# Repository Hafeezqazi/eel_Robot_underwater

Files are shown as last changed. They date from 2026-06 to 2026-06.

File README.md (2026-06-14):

# 🐟 Bio-Inspired Underwater Eel Robot

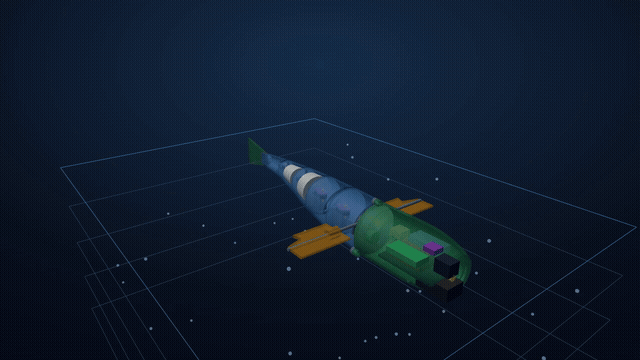
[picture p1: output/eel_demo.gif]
Eel robot swimming and diving


*Travelling-wave swim, a bow-plane dive through the depth rings, and a see-through
body showing the internals (battery, ESP32, foam, keel) — a deterministic
**HyperFrames** render of the actual 3D scene (`cad/make_video.py`).
▶ [Full-quality MP4](output/eel_demo.mp4).*

### 🖥️ [▶ Open the live 3D viewer &amp; datasheet](https://hafeezqazi.github.io/eel_Robot_underwater/)
*Runs right in your browser — interactive 3D model, internals, motion, and all the
engineering numbers. No install. (Or open `eel_design.html` / `eel_viewer.html`
straight from the repo root.)*

A ~50 cm anguilliform (eel-style) underwater robot: a free-flooding, segmented
body that swims with a travelling body wave, dives with bow planes, and carries a
camera + light in a sealed head. Tethered, 3D-printable, desk/pool scale.

This repo is a **complete digital design package** — parametric CAD,
first-principles engineering analysis, ESP32 control firmware, full build docs,
and a researched BOM. The whole pipeline regenerates and self-checks at
**28/28** (`python verify_all.py`). It is a *verified design*, not yet a
physically-built robot.

### Start here
- 📄 **[Full design report](PROJECT_REPORT.md)** — the story + every decision, in plain language.
- 🖥️ **[Interactive viewer + datasheet](https://hafeezqazi.github.io/eel_Robot_underwater/)** — live in your browser (3D model, internals, all the numbers; no install), or open [`eel_design.html`](eel_design.html) from the repo root.
- 🛠️ **[Build guide](docs/build_guide.md)** · 🧾 **[BOM](docs/BOM.md)** · 🏭 **[Manufacturing](docs/manufacturing.md)** · 🔌 **[Wiring](docs/wiring_pinout.md)**

### Reproduce it
```bash
pip install cadquery numpy matplotlib
python verify_all.py          # regenerates all parts + reports, checks 28/28
```

### Headline numbers (predicted — confirm in the tank)
| | |
|---|---|
| Size / mass | 500 × 70 mm / ~390 g dry |
| Stability | neutral buoyancy, roll +8 mm, ~2° trim |
| Cruise (predicted) | ~0.53 m/s, 2 Hz tail-beat, Strouhal 0.22–0.44 |
| Depth | rated 2 m (head bay good to ~84 m before buckling) |
| Power | ~6.7 W avg, sized for ~4 A peak |

### Status
✅ Digital design complete + validated (CAD, analysis, firmware source, docs, BOM).
⬜ Physical build remains (compile/flash firmware, buy exact parts, print, seal,
wet-test) — these need hardware, by design. See the report's "done vs. next".

---
*Built as a code-driven parametric design. Single source of truth:
[`cad/params.py`](cad/params.py).*

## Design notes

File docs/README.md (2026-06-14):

# Bio-Inspired Underwater Eel Robot

A from-scratch design package for an **anguilliform (eel) underwater robot** —
a ~500 mm desk/pool prototype that swims by undulating a chain of **5 revolute
joints** (front 3 servo-driven), with **bow dive planes for active depth
control (3-D diving)** and an **FPV camera + LED headlight** looking out a
clear nose window — so it's a usable mini-ROV, not just a swimmer. Everything
here is parametric and runnable: change one number in `cad/params.py` and the
CAD geometry, the physics sizing, and the gait all update together.

> Scope: desk/pool prototype tier — ~50 cm, shallow (<2 m), tethered,
> 3D-printed, hobby metal-gear servos. Re-parameterize to scale up.

---

## 1. What's in the box

```
eel_robot/
├─ cad/                 CadQuery parametric CAD (run these to get STEP/STL)
│  ├─ params.py         SINGLE SOURCE OF TRUTH — all dimensions & physics
│  ├─ joints.py         revolute joint hardware (tongue + clevis + pin)
│  ├─ body.py           tapered free-flooding body segments (seg1..seg5)
│  ├─ head_bay.py       sealed dry electronics bay + O-ring lid
│  ├─ assembly.py       full kinematic chain → STEP / SVG / print STLs
│  ├─ dive_planes.py    bow dive planes (active depth control → 3-D)
│  ├─ skin.py           flexible TPU skin sleeve (covers joint gaps)
│  ├─ test_rig.py       bollard-thrust test cradle (bench tool)
│  ├─ test_coupons.py   fit/seal coupons (servo, potting cup, O-ring)
│  ├─ ballast.py        keel strap, trim rail/carrier, foam retainer
│  ├─ tail_flexure.py   3 TPU passive-tail flexure variants (bench-pick)
│  ├─ hull_solid.py     watertight single hull for CFD meshing
│  ├─ render.py         top-view + dive-plane previews (QA only)
│  ├─ render3d.py       shaded 3-D isometric + orthographic renders
│  ├─ web_viewer.py     → output/eel_viewer.html (interactive browser 3-D)
│  └─ design_page.py    → output/eel_design.html (ALL-IN-ONE shareable page)
├─ analysis/
│  ├─ sizing.py         drag, buoyancy/ballast, gait, torque, power budget
│  ├─ structures.py     pressure-hull stress, buckling depth, pin shear, seal
│  ├─ swim_sim.py       Lighthill self-propulsion + swim_cycle.gif
│  ├─ dive.py           dive-plane lift, min dive speed, descent rate
│  ├─ stability.py      CG vs CB, roll + trim, foam/keel sizing
│  ├─ power.py          peak current, brownout, tether voltage drop
│  ├─ tail_stiffness.py passive-tail spring rate / TPU-flexure thickness
│  └─ dive_linkage.py   dive 4-bar: 1:1 kinematics + servo holding torque
├─ firmware/
│  ├─ gait.py           anguilliform gait generator (Python reference)
│  └─ eel_gait.ino      ESP32 port: PCA9685 + 4 servos + leak cutoff
├─ cfd/                 OpenFOAM steady drag case (you run the solve)
│  ├─ case_setup.py     stage hull STL + report Reynolds / drag
│  ├─ 0/ constant/ system/   standard simpleFoam dictionaries
│  └─ README.md         how to run + read the drag coefficient
├─ docs/
│  ├─ README.md         this file
│  ├─ BOM.md            bill of materials (AliExpress link on every line)
│  ├─ manufacturing.md  materials, print settings, tolerances, sealing
│  ├─ build_guide.md    step-by-step build + build-readiness checklist
│  ├─ joints.md         joint / DOF reference table
│  ├─ wiring_pinout.md  pin-level wiring table (matches eel_gait.ino)
│  └─ wiring.drawio     editable electronics block diagram
├─ verify_all.py       run the whole pipeline, report PASS/FAIL (one command)
└─ output/             all generated artifacts (STEP, STL, SVG, PNG, GIF, TXT)
```

---

## 2. Quick start

```bash
# one-time: install the CAD kernel (large — pulls OpenCascade)
python -m pip install cadquery numpy matplotlib

# regenerate everything
cd cad
python params.py        # prints the parameter/geometry summary
python joints.py        # output/joint_demo.{step,stl}
python head_bay.py      # output/head.stl, output/lid.stl
python body.py          # output/test_seg1.stl, test_seg5.stl
python assembly.py      # output/eel_straight.*, eel_swim.*, print_*.stl
python dive_planes.py   # output/print_dive_plane.stl, print_dive_shaft.stl
python skin.py          # output/print_skin.stl  (flexible sleeve)
python test_rig.py      # output/print_test_rig.stl
python hull_solid.py    # output/cfd_hull.{stl,step}
python render.py        # output/preview_*.png  (top + dive views)
python render3d.py      # output/render3d_iso.png, render3d_views.png (shaded 3-D)
python joint_detail.py  # output/joint_detail.png (exploded joint close-up)
python web_viewer.py    # output/eel_viewer.html (interactive, animated, browser)

cd ../analysis
python sizing.py        # output/sizing_report.txt
python structures.py    # output/structures_report.txt
python swim_sim.py      # predicted cruise speed + output/swim_cycle.gif
python dive.py          # output/dive_report.txt  (dive performance)
python stability.py     # output/stability_report.txt  (CG/CB, roll, trim, foam/keel)
python power.py          # output/power_report.txt  (peak current, tether drop)
python tail_stiffness.py # output/tail_stiffness_report.txt  (flexure/band sizing)
python dive_linkage.py   # output/dive_linkage_report.txt  (1:1 kinematics + torque)

cd ../firmware && python gait.py       # prints the servo command table

# optional CFD drag study (needs OpenFOAM on Linux/WSL/Docker):
cd ../cfd && python case_setup.py && ./Allrun
```

Or just run everything and check it all still passes:

```bash
python verify_all.py     # runs every script in order → PASS/FAIL table
```

Open `output/eel_swim.step` in any CAD viewer (FreeCAD, Fusion, Onshape) to
inspect the articulated assembly; slice `output/print_*.stl` to 3D-print.

> Tested with Python 3.13 + cadquery 2.7.0. If `pip install cadquery` fails on
> your Python, create a 3.11/3.12 virtual-env — OCP wheels are most reliable
> there.

---

## 3. Key results (current parameters)

> **Predicted, not validated.** Every performance number below (speed, drag,
> Strouhal, dive, descent) is a first-order *estimate* from the analysis scripts
> — assumed `Cd`, Lighthill EBT with a 0.5 derate, **no CFD solve and no wet
> test**. Treat them as design targets to confirm in the tank, not measured
> results. Geometry/mass/buoyancy/torque are computed from the CAD and are firmer.

| Quantity | Value | Source |
|---|---|---|
| Length × max dia | 500 × 70 mm (nose truncated at z=18 for the window) | `params.py` |
| DOF | 3 driven + 2 passive body joints + dive planes (4 servos total) | `params.py` |
| Joint travel | ±28° | `params.py` |
| Payload | analog FPV camera + dimmable LED headlight behind a Ø30 acrylic nose window | `head_bay.py` |
| Displaced volume | ~1105 cm³ | `sizing.py` |
| Dry mass | ~390 g (4 servos + camera + LED) | `sizing.py` |
| Inherent buoyancy (free-flood) | +150 g positive (add ballast to neutral) | `sizing.py` |
| Cruise drag @ 0.3 m/s | ~17 mN | `sizing.py` |
| Tail-beat frequency | 2.0 Hz (cruise) | `params.py` |
| Cruise joint amplitude | 7° (28° max in reserve) | `params.py` |
| Predicted cruise speed | ~0.53 m/s (1.1 BL/s) realistic; 1.07 m/s EBT upper bound | `swim_sim.py` |
| Strouhal | 0.22 at the EBT speed; ~0.44 at the derated speed (pool-tune) | `swim_sim.py` |
| Dive planes | 63 cm² (2 fins, 1 servo), ±25°, root clear of hull+skin | `dive.py` |
| Min dive speed / descent rate | 0.24 m/s / ~0.5 m/s | `dive.py` |
| Servo torque margin | ~40× (at full ±28° travel) | `sizing.py` |
| Electrical load | ~6.7 W incl. 2 W light (0.91 A @ 7.4 V) | `sizing.py` |
| Pressure-hull collapse depth | ~84 m (rated 2 m) | `structures.py` |
| Joint-pin shear SF | ~13× | `structures.py` |
| O-ring squeeze | 25% (ideal 15–30%) | `structures.py` |
| Hull vol. CAD vs analytic | 1105.9 vs 1104.8 cm³ (0.1%) | cross-check |

Design previews (straight, mid-stroke, and the animated swim cycle):

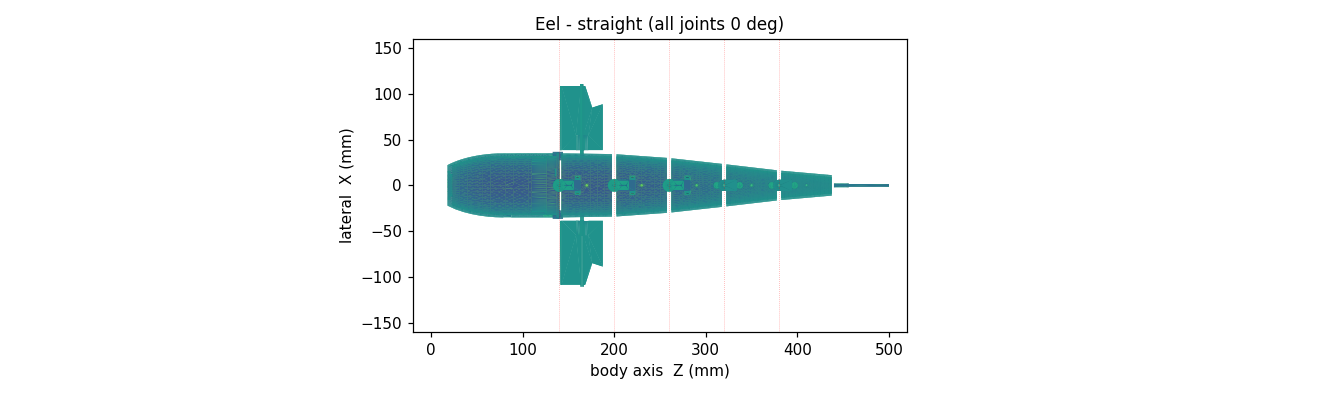
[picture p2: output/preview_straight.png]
straight

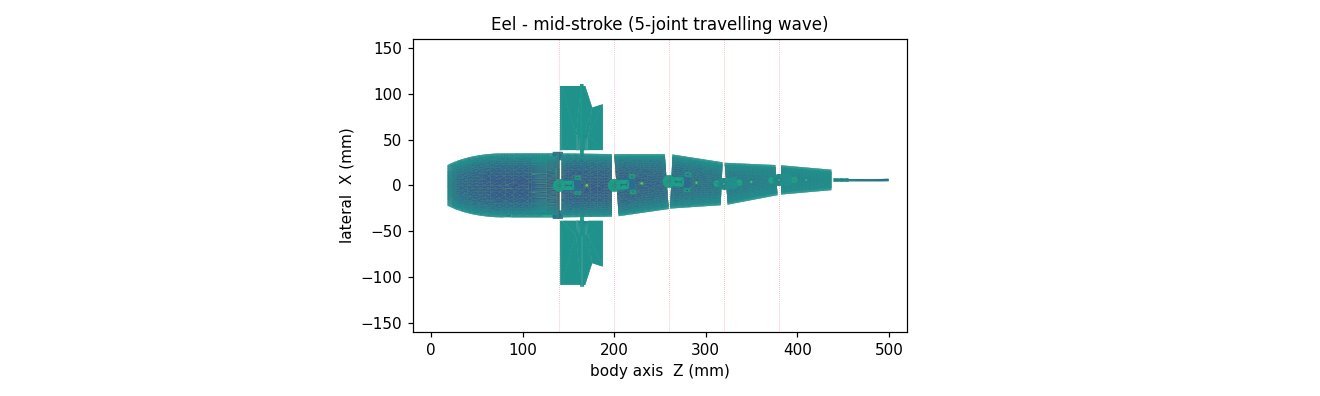
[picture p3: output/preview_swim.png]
swim

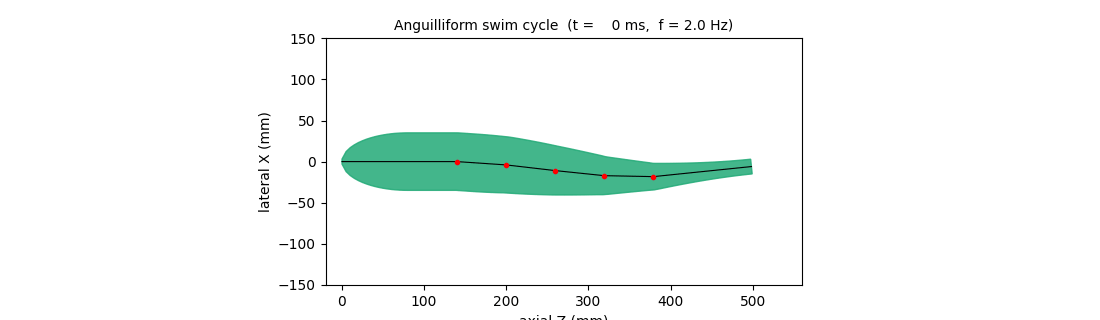
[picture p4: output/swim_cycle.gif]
cycle

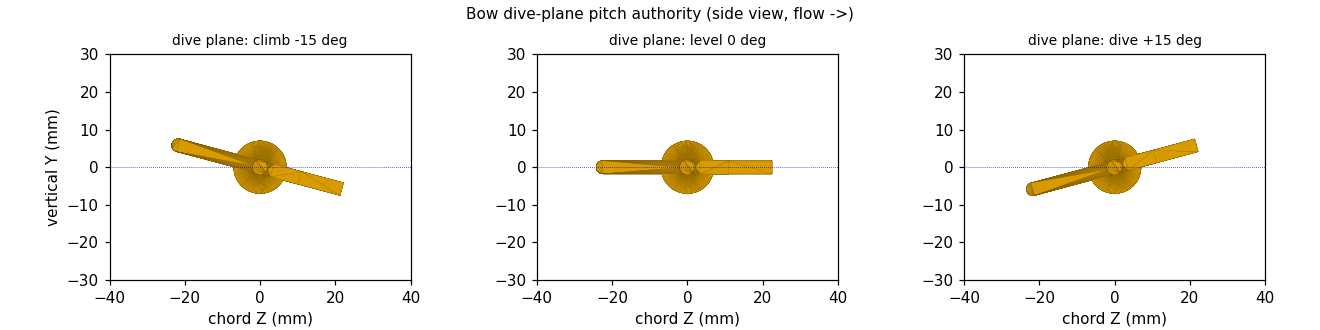
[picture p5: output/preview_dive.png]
dive


Shaded 3-D (`cad/render3d.py`):

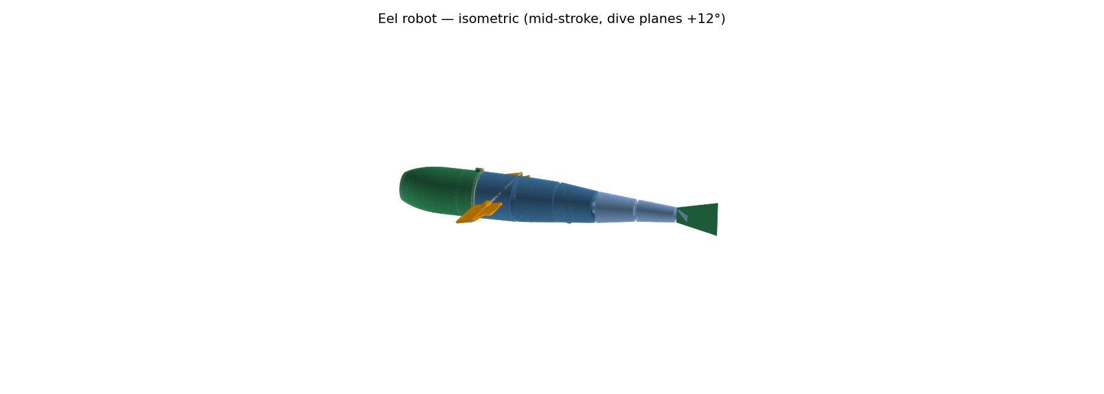
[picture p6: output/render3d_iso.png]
iso

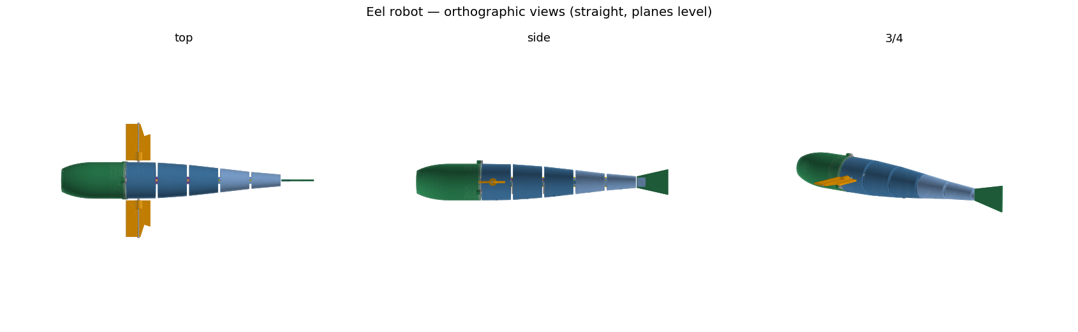
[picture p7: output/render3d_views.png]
views


How one joint goes together (`cad/joint_detail.py`) — pin = hinge, servo+horn
drives the front 3, rubber band springs the back 2:

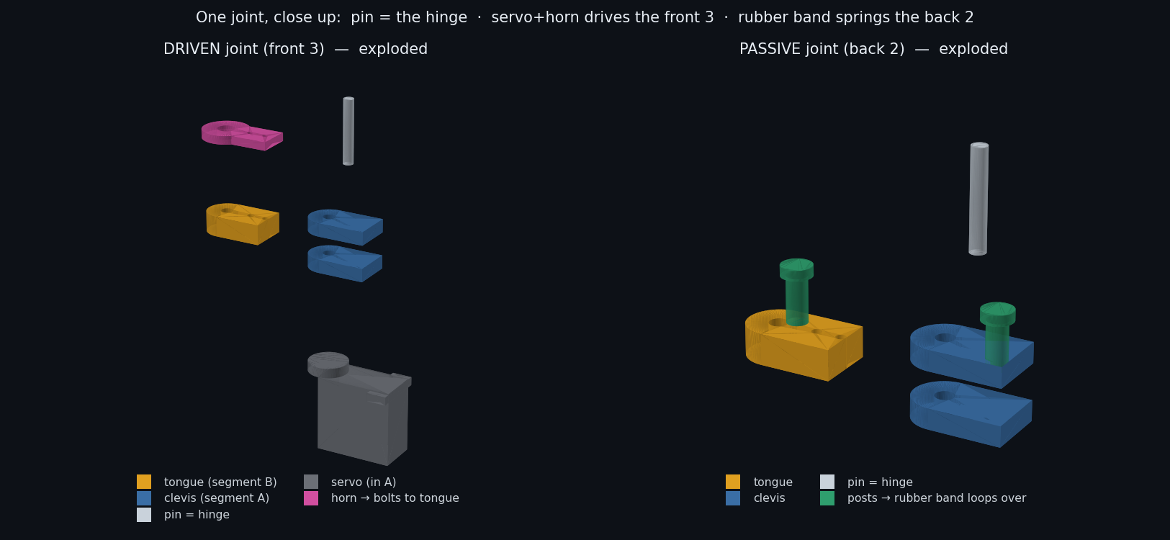
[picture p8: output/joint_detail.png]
joint


How the servo mounts inside a segment — drops in, flanges screw to two printed
bosses, shaft up to the horn:

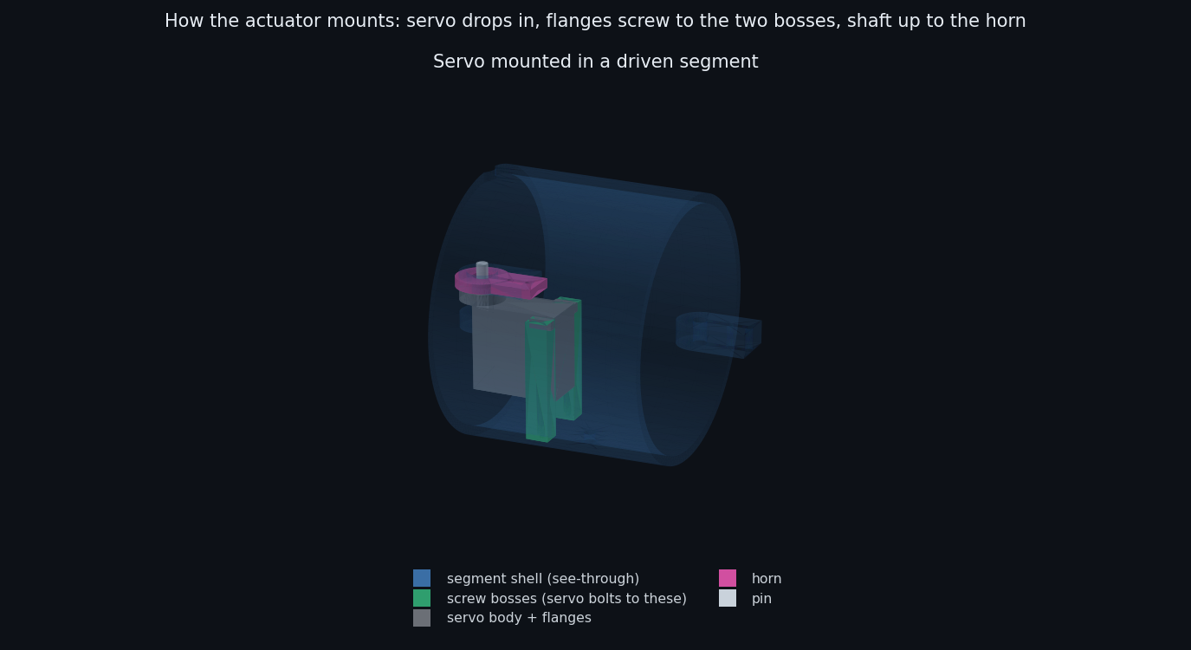
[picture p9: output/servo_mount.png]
mount


**★ THE shareable design page — `output/eel_design.html`** (built by
`cad/design_page.py`): one self-contained file with the live swimming 3-D fish
**plus** a spec dashboard, a clickable parts catalogue (click a part → it
highlights on the fish and shows material / size / power / qty / price / **where
to buy**), and the full BOM with buy links. This is the single file to share.

**Minimal viewer — `output/eel_viewer.html`** (built by `cad/web_viewer.py`):
just the live 3-D model + controls, no catalogue. Lighter if you only want the
geometry. Both double-click to open; three.js loads from a CDN (internet on
first open).

**To view in proper CAD (rotatable, measurable):** open `output/eel_swim.step`
or `eel_straight.step` in **SolidWorks** (File → Open → the `.step`), FreeCAD,
Fusion 360, or Onshape. STEP imports as a full solid assembly.

---

## 4. Design decisions you should confirm

1. **Free-flooding vs. fully sealed body.** A sealed 70 mm body displaces
   ~1.1 L and would need ~740 g of ballast — heavier than the whole robot.
   The package therefore assumes **free-flooding tail segments** (water fills
   seg1..seg5 through printed drain holes, the waterproof servos run wet) with
   only the **head bay sealed**. That drops ballast to ~150 g. If you want a
   fully sealed body instead, each segment needs end bulkheads + shaft seals
   and a lot of buoyancy trim.

2. **Skin sleeve.** The segmented body has gaps at each joint (visible in the
   swim preview). A flexible **TPU/silicone sleeve** over the spine restores a
   smooth hydrodynamic surface and keeps debris out. It is modeled in
   `cad/skin.py` (→ `print_skin.stl`, with flex grooves at each joint and
   clearance holes where the dive shaft exits); print it in TPU or use it as
   a mould core for silicone.

3. **Diving is dynamic, not static.** The bow dive planes give 3-D depth
   control but need forward flow: the robot dives/climbs **while swimming** and
   holds depth by neutral trim. It **cannot hover-descend at zero speed** — for
   that you'd add a variable-buoyancy engine. Performance in `analysis/dive.py`.

4. **Front 3 joints driven, rear 2 passive (compliant tail).** A 9 g servo
   won't fit the thin tail (seg5 is only ~32 mm dia), so the last two joints
   carry **no servo** — they're a springy tail the body wave flexes on its own,
   like a real fish. Fewer servos also means lighter + more buoyant. Rubber
   bands loop between **printed anchor posts** (in the segment STLs, hanging
   from the shell ceiling either side of each passive joint); tune band count/
   tension to the ~2 Hz beat — or swap in a TPU flexure / silicone element.

5. **The lid carries the joint-1 tongue and all three penetrations.** The
   drivetrain plugs into the back of the lid; tether gland +12 mm above the
   axis, epoxy-potted servo/leak wire gland −12 mm below, MS5837 sensor port
   at x = +14 mm (the sensor reads ambient pressure through the flooded seg1
   behind the lid). Unpin joint 1 → the lid and the electronics tray slide
   straight out.

6. **Camera + light = the payload.** An analog FPV camera (5 V, composite out)
   and a 1–3 W LED sit *inside the dry bay* behind a Ø30 acrylic disc bonded
   into the truncated nose — zero extra waterproofing. Video runs topside on a
   spare tether pair into a $8 USB capture dongle; the light dims over serial
   (`W 0..1`). WiFi/digital cameras were rejected: 2.4 GHz dies in centimetres
   of water; composite-video-over-a-pair is the proven cheap-ROV approach. The
   flat nose face costs a little drag vs. the ogive tip — the staged CFD case
   can estimate/check that difference **once you solve it** (it isn't solved here).

---

## 5. Division of labor

**Software / design (in this repo):** all parametric CAD scripts + the revolute
joints, the physics/sizing math, the gait generator + ESP32 firmware, the wiring
diagram, the BOM, and these docs — all parametric, so any parameter change
re-derives the geometry and the analysis.

**Physical build (off-repo):** run the scripts, inspect/print the STLs, buy
parts, assemble, waterproof the head bay, wire & solder, run CFD if desired, and
do the physical pool testing. Organic skin/nose surfacing is the one CAD piece
best done by hand in a GUI.

---

## 6. Build sequence

Cheap coupons + fits **first**, then the body. Pass/fail thresholds: `build_guide.md` §12.

1. **Print the coupons** (`coupon_servo.stl`, `coupon_oring_bore/plug.stl`,
   `coupon_potting.stl`) → confirm your servo fits its pocket, the O-ring seals
   on *your* printer, and a potted wire bundle survives a soak. Don't print the
   body until these pass.
2. **Print one segment + the joint demo** → confirm the clevis/tongue/pin fit
   and the revolute moves freely. Tweak `PIN_CLEAR`, `CLEVIS_GAP` in `params.py`.
3. **Print head + lid** → bond the nose window, fit electronics, fit the 3 M3
   lid-clamp ears; **dry sink/seal test the empty bay first**, then pot the wire
   gland + sensor port (`manufacturing.md` §6).
4. **Print seg1..seg5 + tail fin + the TPU flexures** (`print_flexure_*.stl`);
   assemble the chain with pins + servos. The passive tail is a **TPU flexure**
   (bench-pick the variant that hits f_n, §12); rubber bands over the anchor
   posts are the **fallback**, not primary.
5. **Print + fit the ballast hardware** (`print_keel_strap.stl`,
   `print_trim_rail.stl`, `print_trim_carrier.stl`, `print_foam_retainer.stl`).
6. **Compile + flash `eel_gait.ino`** (ESP32 core 2.0.x + Adafruit PWM +
   BlueRobotics MS5837 — **compile it yourself; the source is not
   compile-verified in this repo**). Bench-test the travelling wave (servos
   sweeping in phase), the camera (USB capture) and the headlight (`W 0.5`).
7. **Ballast & trim** in a tub to neutral buoyancy (~150 g, see `sizing.py`).
8. **Tethered pool test** → tune amplitude/frequency/heading; measure speed vs.
   the Strouhal target. Iterate parameters → re-print affected parts.

> ⚠️ Always do the **dry pressure/leak test of the head bay before any powered
> submersion.** The firmware halts on a leak, but seal first, trust second.

---

## 7. Validation (analysis stage D) — what's already built

- **Gait phasing:** `firmware/gait.py` generates + sanity-checks the
  travelling-wave commands (software reference; not a wet test).
- **Self-propulsion:** `analysis/swim_sim.py` predicts cruise speed (Lighthill
  EBT) and renders `output/swim_cycle.gif`. EBT is an upper bound (×0.5 derate
  → realistic estimate).
- **Structure/sealing:** `analysis/structures.py` confirms the hull, pin, and
  O-ring have large margins at the 2 m rating (bay good to ~84 m).
- **CFD drag:** `cfd/` only **stages** a `simpleFoam` case (geometry + Reynolds
  + an analytic drag estimate); it is **not solved here**. Run it on
  Linux/WSL/Docker to get a measured drag coefficient, then feed it back into
  `CD_AXIAL` in `params.py` and re-run sizing/swim_sim — the loop.
- **Bench:** print `print_test_rig.stl`, mount the robot, tether to a force
  gauge → measured bollard thrust vs. `swim_sim.py`. Then free-swim speed run.

---

## 8. Open items (not blocking)

- Exact servo model → set `SERVO_BODY_*` and `SERVO_TORQUE_RATED` in `params.py`.
- 3D-printer build volume → may force splitting longer parts.
- Tether length + topside controller (laptop USB-serial vs RC).

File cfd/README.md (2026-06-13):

# CFD case — steady drag study (OpenFOAM)

A ready-to-run **simpleFoam** case that computes the **parasitic drag** of the
rigid eel hull and a drag coefficient, to validate the `CD_AXIAL = 0.10`
assumption used in `analysis/sizing.py`. Flow is along **+Z** (the body axis).

> This is the **rigid-body drag** study. The *swimming thrust* is a separate,
> much harder moving-boundary problem (overset / dynamic mesh) — see "Going
> further" below. For first-order design, drag here + Lighthill thrust in
> `analysis/swim_sim.py` is enough to size the robot.

## Prerequisites

- **OpenFOAM** (v2012+ / .org v9+). Not native on Windows — use **WSL2**,
  a Linux box, or the **openfoam Docker image**.
- The hull surface `output/cfd_hull.stl` — generate it first:
  ```bash
  cd ../cad && python hull_solid.py
  ```

## Run

```bash
cd cfd
python case_setup.py     # copies the STL in, prints Re and the analytic drag
./Allrun                 # blockMesh -> snappy -> simpleFoam (needs OpenFOAM)
```

Watch convergence (`log.simpleFoam`); residuals should drop below 1e-4.

## Get the answer

```bash
# drag force & coefficient history:
cat postProcessing/forces/0/coefficient.dat
```
- **Cd** column (once converged) is the drag coefficient on the reference area
  `Aref = 0.00385 m^2` (frontal). Compare to the `0.10` assumed in sizing.
- If CFD Cd differs, update `CD_AXIAL` in `cad/params.py` and re-run
  `analysis/sizing.py` + `analysis/swim_sim.py` to refresh the speed/power
  predictions. **This is the validation loop.**

## What's set

| Item | Value | File |
|---|---|---|
| Inlet speed | 0.5 m/s (+Z) | `0/U`, `controlDict` magUInf |
| Water ν | 1e-6 m²/s | `constant/transportProperties` |
| Reynolds | ~2.5e5 (turbulent) | — |
| Turbulence | k-ω SST RANS | `constant/turbulenceProperties` |
| Domain | 0.7×0.7×2.2 m box | `system/blockMeshDict` |
| Surface refinement | snappy level 2–3 | `system/snappyHexMeshDict` |
| Wall layers | **off** (enable for y⁺ study) | `snappyHexMeshDict` |

To sweep speed, change `0/U`, `controlDict` `magUInf`, and the value in
`case_setup.py`, then re-run — drag should scale ≈ U².

## Going further (swimming thrust)

The undulating-body thrust needs the joints to move the surface in time:
- **overset mesh** (one background + a body mesh per segment) driven by the
  gait, or **dynamicMotionSolverFvMesh** with prescribed boundary motion from
  `firmware/gait.py`, solved with `pimpleFoam` (transient).
- That's a multi-day setup; ask and I can scaffold it next. For now the
  rigid-drag Cd + Lighthill EBT give a validated first-order speed/power.

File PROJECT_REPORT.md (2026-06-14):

# Bio-Inspired Underwater Eel Robot — Design Report

*A walkthrough of the design, in my own words, for the team.*

> **TL;DR** — I designed a ~50 cm anguilliform (eel-style) underwater robot from
> scratch: a free-flooding, segmented body that swims with a travelling body
> wave, dives with bow planes, and carries a camera + light in a sealed head.
> The **digital design is complete and self-consistent** — parametric CAD,
> first-principles engineering analysis, control firmware, full build docs, and a
> researched bill of materials. The whole thing regenerates and self-checks at
> **28/28** on one command, and it was hardened over **several rounds of design review**.
> What's left is the physical build (print, buy parts, seal, wet-test) — those
> steps need hardware, not more design.

---

## 1. What I set out to build

A small, tethered, 3D-printable underwater vehicle inspired by how an eel
actually swims — not a propeller sub. Goals:

- **Bio-inspired propulsion:** an undulating body wave (anguilliform), like a
  real eel, instead of a thruster.
- **3D capable:** it cruises, turns, and **dives/climbs**, holding depth.
- **Desk/pool scale:** ~500 mm long, ~70 mm diameter, shallow water, tethered for
  power + control + video — simple enough to actually build and test.
- **Useful payload:** a forward camera + headlight so it can *see*.

## 2. The big design decisions (and why)

| Decision | Why I went this way |
|---|---|
| **Free-flooding body, sealed head only** | Sealing a long jointed body is a leak nightmare. Let the body flood; only the head (electronics) is dry. Far simpler + safer. |
| **3 driven joints + 2 passive tail joints** | Servos drive the front of the wave; a compliant TPU/rubber tail finishes it for free — fewer motors, more eel-like motion. |
| **Bow dive planes for depth** | Like a submarine's hydroplanes — pitch the nose to dive/climb at speed. Cheap, robust, one extra servo. |
| **Buoyancy foam + lead keel** | A free-flooding body floats nose-up and rolls. Closed-cell foam (aft) + a low forward lead keel fix trim *and* roll. |
| **Tether (12 V) + buck at the robot** | No batteries to size for endurance, no comms-through-water problem; video + serial ride spare tether pairs. |
| **Camera + light behind a nose window** | They stay dry inside the head and look out through a bonded acrylic disc — zero extra waterproofing. |

## 3. How I worked (the pipeline)

I built this as **code-driven parametric design**, so every part traces back to
one source of truth and the whole thing is reproducible:

```
concept → first-principles math → parametric CAD → engineering analysis
        → electronics + firmware → build docs + BOM → design review
```

- **One parameter file** (`cad/params.py`) drives all geometry and feeds the
  analysis — change the body length or a servo size and *everything* re-derives.
- **One command checks everything**: `python verify_all.py` runs all 28 scripts
  (CAD exports + analysis + renders) and reports pass/fail. It's green.

## 4. The vehicle, part by part

- **Head bay** — the only sealed compartment: holds the ESP32, battery buffer,
  IMU, depth sensor, camera + LED. A removable lid (radial O-ring seal + the
  joint-1 pin + 3 M3 bolt ears) lets the electronics tray slide out.
- **Body segments (×5)** — tapered, free-flooding shells; the front 3 each hold a
  servo that drives that joint; the rear 2 are the passive compliant tail.
- **Joints** — simple clevis + tongue + stainless pin hinges; a 5 mm inter-segment
  gap so they never collide when the body bends.
- **Dive planes** — two bow fins on one shaft, driven together by a fourth servo.
- **Skin** — a flexible TPU sleeve over the segmented spine for clean flow (the
  body still floods through drain holes underneath — the foam still works because
  closed-cell foam seals *itself*).
- **Ballast** — bore-fitting closed-cell foam discs + a lead keel + a small
  sliding trim weight for final levelling in the water.

## 5. Does it actually work? (the engineering checks)

Every claim below is **computed from first principles** — these are *predictions*
to confirm in the tank, not measured results, and the docs are explicit about
that. Headline numbers at the current parameters:

| Quantity | Value |
|---|---|
| Size / displaced volume | 500 × 70 mm / ~1105 cm³ |
| Dry mass / inherent buoyancy | ~390 g / **+150 g positive** (floats; ballast to neutral) |
| **Stability** | **neutral buoyancy, roll margin +8 mm, ~2° resting trim** |
| Predicted cruise speed | **~0.53 m/s** (~1.1 body-lengths/s), 2 Hz tail-beat |
| Strouhal number | 0.22–0.44 (in the efficient swimming band) |
| Dive planes | 63 cm², ±25°, min dive speed ~0.24 m/s |
| Structure | large margins to the 2 m rating; head bay good to ~84 m before buckling |
| Electrical | ~6.7 W average; sized for ~4 A peak (all servos stall) |

The analysis scripts that produce these: buoyancy/sizing, **CG-vs-CB stability**,
structures/sealing, **power + brownout + tether drop**, Lighthill self-propulsion,
dive-plane lift, passive-tail stiffness, and dive-linkage kinematics. A CFD case
is **staged** (not solved) for whoever wants a measured drag number later.

## 6. Electronics & control

- **Brains:** ESP32 + a PCA9685 driver for the 4 servos, an MPU6050 IMU, an
  MS5837 depth sensor, and a leak probe.
- **Firmware** generates the travelling-wave gait and adds two closed loops:
  **heading-hold** (IMU) and **depth-hold** (dive planes). Both are gated on their
  sensor actually responding, and both are labelled **experimental / bench-tune**
  — honest, because they aren't tested on hardware yet.
- **Power:** 12 V down the tether, bucked to a 5–6 V servo bus + a separate MCU
  rail at the robot, with a bulk cap + fuses to survive servo stall spikes.

## 7. Design review & hardening

I put the whole package through **several rounds of structured design review**,
fixing real issues each round: a depth-sensor stub, a heading-controller bug, a
power-wiring conflict, a missing lid clamp, stale docs, and more — re-verifying
the pipeline (28/28) after each. The honest end state: *a strong digital design
package; one firmware compile + real-world validation away from a finished
robot.* That's exactly the
boundary below.

## 8. Where it stands: done vs. next

**Done (and validated in software):**
- ✅ Full parametric CAD → printable STLs + STEP assemblies
- ✅ First-principles engineering analysis (28/28 pipeline)
- ✅ Control firmware (source) + wiring + pin map
- ✅ Build guide, assembly sequence, test coupons with pass/fail
- ✅ BOM with researched parts + a clear servo-selection finding

**Next (physical — needs hardware, by design):**
- ⬜ Compile/flash the firmware and bench-tune the PID loops
- ⬜ Commit to exact purchase SKUs (I researched concrete starting picks)
- ⬜ Print, seal, and **dry leak-test the head bay first**
- ⬜ Ballast to neutral, then tethered pool test → measure speed vs. prediction

> One honest finding worth flagging to the team: genuinely-submersible (IP67)
> servos are either too bulky for this body or heavier than the ballast can
> absorb. So the build-ready choice here is a **cheap metal-gear micro that we
> pot for submersion**; a drop-in IP67 servo would mean a slightly longer hull.
> Both options are written up in the BOM.

## 9. How to explore it (for the team)

1. **Just look:** open `output/eel_design.html` in any browser — a 3D viewer +
   datasheet with the internals, motion, and all the engineering numbers. No
   install needed; great for sharing.
2. **Reproduce it:** install CadQuery (`pip install cadquery`) and run
   `python verify_all.py` — regenerates every part + report (28/28).
3. **Build from it:** `docs/build_guide.md` (step-by-step + test coupons),
   `docs/BOM.md` (shopping list), `docs/manufacturing.md` (print/seal).

## 10. What's in the repo

```
eel_robot/
  cad/         parametric CAD (params.py is the single source of truth)
  analysis/    buoyancy, stability, structures, power, swim, dive, tail
  firmware/    ESP32 gait + heading/depth control (gait.py mirror)
  cfd/         staged OpenFOAM drag case (run it for a measured Cd)
  docs/        build guide, BOM, manufacturing, wiring, joints
  output/      generated STLs, STEP, renders, swim GIF, and the HTML viewer
  verify_all.py  one-command pipeline check (28/28)
  PROJECT_REPORT.md  ← you are here
```

---

*Status: complete digital design package — a verified prototype, not yet a
physically-built robot. The remaining steps are the physical build, which is the
fun part. — [your name]*

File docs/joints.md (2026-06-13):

# Joint / DOF Reference

The eel is a **serial chain of 5 revolute (yaw) joints**. The head is the
fixed base; each driven segment rotates about a vertical pin relative to the
part ahead of it. All values are generated from `cad/params.py` — re-run
`python params.py` and `python gait.py` to regenerate after any change.

## Joint hardware (every joint identical in kind)

```
   part AHEAD (forward)            part BEHIND (aft)
   ───────────────┐                ┌───────────────
        TONGUE  ──┼──►   ((pin))  ◄┼──  CLEVIS (fork)
   (single blade) │   vertical Y    │  (two prongs straddle the tongue)
   ───────────────┘    pin axis     └───────────────
                         ▲
                    SERVO output shaft (in the aft part) is coaxial with the
                    pin and clamps the tongue → energising it yaws the aft part.
```

- **Type:** revolute, 1 DOF each, rotation about the global **Y (vertical)**
  axis → **yaw** (side-to-side), the swimming plane.
- **Travel:** ±28° mechanical (`JOINT_TRAVEL_DEG`).
- **Pin:** 3 mm dowel / M3 (`PIN_D`), bore clearance `PIN_CLEAR` = 0.3 mm.
- **Drive:** one waterproof servo housed in the aft segment, shaft on the pin
  axis, horn clamped to the forward part's tongue (direct drive, no linkage).

## Joint table

| Joint | Station z (mm) | Connects | Drive | Body radius here (mm) |
|---:|---:|---|---|---:|
| 1 | 140 | head → seg1 | **servo** (in seg1) | 35.0 |
| 2 | 200 | seg1 → seg2 | **servo** (in seg2) | 34.1 |
| 3 | 260 | seg2 → seg3 | **servo** (in seg3) | 29.8 |
| 4 | 320 | seg3 → seg4 | *passive* (compliant) | 23.2 |
| 5 | 380 | seg4 → seg5 | *passive* (compliant) | 16.2 |

**Joints 4–5 are passive** — no servo. A 9 g servo won't fit the thin tail
(seg5 ~32 mm dia), so the rear two joints are a **springy compliant tail** the
body wave flexes on its own (biomimetic). Each passive joint has a pair of
**printed anchor posts** (hanging from the shell ceiling, one each side of the
pivot — already in the segment STLs); loop a rubber band between them and tune
band count/tension so the tail naturally undulates at the ~2 Hz beat. A TPU
flexure or silicone element works as an alternative spring.

**Segment gap:** adjacent shells are spaced **8 mm apart** (`SEGMENT_GAP`) so
they don't collide when the joint bends — the clevis/tongue/pin bridge the gap,
and the flexible skin sleeve covers it. Without the gap the rigid shells overlap
on any bend.

Tail fin: passive, **bolted** to seg5 rear (no DOF).

## Kinematics (forward chain)

`assembly.py` poses the body by marching the chain: each segment is placed at
its joint pivot and rotated by the **cumulative** sum of joint angles, so a
joint-angle vector `[θ1..θ5]` fully determines the pose. The pivot of joint
i+1 advances from joint i by the segment length rotated into the current
heading.

## Gait phasing (from `firmware/gait.py`)

Travelling body wave `θ_i(t) = A_i·sin(2π f t − φ_i) + heading`:

| Joint | Phase lag φ (deg) | Cruise amplitude A (deg) |
|---:|---:|---:|
| 1 | 101 | 3.9 |
| 2 | 144 | 4.7 |
| 3 | 187 | 5.4 |
| 4 | 230 | 6.2 |
| 5 | 274 | 7.0 |

- **f** = 2.0 Hz cruise. Strouhal ≈ 0.22 at the EBT-predicted speed (efficient
  band); at the ×0.5-derated realistic speed it reads ~0.44 — typical of hobby
  robotic swimmers. Pool-tune amplitude/frequency with the `S`/`H` commands.
- Cruise amplitude peaks at 7° (`CRUISE_AMP_DEG`); the ±28° mechanical travel
  is reserve for turns/bursts. Amplitude grows head→tail (anguilliform).
- **Servos drive joints 1–3** (`gait.command()` returns 3 angles). Joints 4–5
  (the compliant tail) **follow the same wave passively** — `gait.body_wave_angles()`
  returns all 5 for the sim/animation.
- A constant `heading` bias added to the driven joints steers the robot (turn).

## Extra DOF — bow dive planes (depth control)

Beyond the 5 swim joints, a **4th servo** pitches a pair of bow dive planes
about the transverse **X** axis (`DIVE_PLANE_Z`, ±25°). This is a **pitch** DOF
(not part of the undulation chain) that generates vertical lift while swimming
→ 3-D diving. Driven open-loop or by the `DepthHold` PD controller in
`firmware/gait.py`. Convention: **+angle = dive**. No authority at zero speed.

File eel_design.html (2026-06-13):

❚❚ spin

speed

dive

internals

reset view

drag orbit · scroll zoom · click a part

Depth 0.00 m · angle the fins + speed up to dive

# Bio-Inspired Eel Robot

Anguilliform underwater vehicle · full design datasheet

Every number on this page is computed/predicted from the design model — not yet physically validated (no CFD solve, no wet test). Speed, drag, dive and Strouhal are estimates; depth-hold and heading-hold are closed-loop but bench-untested. Use the tabs for power, buoyancy, motion, structure and the full analysis reports.

## Parts — click to highlight & buy

head/tail body dive planes internals

## Full bill of materials

Part | Qty | Material | ~$ | Buy

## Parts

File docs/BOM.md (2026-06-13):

# Bill of Materials — Eel Robot (desk/pool prototype)

Quantities for one robot. Prices are rough ballpark (USD, hobby sources) to
size a budget — verify with your supplier. Every line has an **AliExpress
search link** (cheapest route, 2-4 week shipping); Amazon equivalents exist
for all of them if you need it this week. Swap any line and update the
matching value in `cad/params.py` / `analysis/sizing.py`.

> **Materials, print settings, tolerances, sealing procedure → see
> [manufacturing.md](manufacturing.md).** This file is the shopping list; that
> file is how each part is made and sealed.

> ⚠️ **This is a REFERENCE (class-level) list, not an approved-SKU list.** The
> links are *search* links to a part *class*; pick the exact model, confirm
> dimensions / IP rating / current, and record it in **§ Exact chosen parts**
> below before calling the build purchase-ready. The servo especially drives the
> CAD fit — set `cad/params.py` to whatever you actually buy and re-export.

## Actuation
| # | Item | Qty | Notes | ~$ | Buy |
|---|---|-----|---|----|-----|
| 1 | Metal-gear servo, **~9–20 g, ≥2.5 kg·cm @ 6 V** | 4 | 3 front joints + 1 dive-plane; **truly submersible or pot it** (splash-rated ≠ submerged — see manufacturing §8); sets `SERVO_BODY_*` in params | 40 | [AliExpress](https://www.aliexpress.com/wholesale?SearchText=waterproof+metal+gear+servo+submersible) |
| 2 | Servo horn + M2 hardware | 4 | clamps tongue / dive crank (often included with servo) | 4 | [AliExpress](https://www.aliexpress.com/wholesale?SearchText=9g+servo+horn+arm+set) |
| 2b | 4 mm stainless rod ~225 mm + 2 flanged bushings (4 mm ID) + M2 pushrod wire | 1 set | dive-plane shaft; fins + crank are printed (`dive_planes.py`) | 8 | [AliExpress](https://www.aliexpress.com/wholesale?SearchText=4mm+stainless+steel+round+rod) · [bushings](https://www.aliexpress.com/wholesale?SearchText=4mm+flanged+bushing+brass) |
| 2c | Rubber bands (or TPU flexure / silicone) for the compliant tail | ~10 | rear 2 joints are PASSIVE — bands loop over printed anchor posts; tune count/tension to the ~2 Hz beat | 3 | [AliExpress](https://www.aliexpress.com/wholesale?SearchText=small+rubber+bands+orthodontic) |

## Electronics (head dry bay)
| # | Item | Qty | Notes | ~$ | Buy |
|---|---|-----|---|----|-----|
| 3 | ESP32 dev board | 1 | controller, runs `eel_gait.ino` | 8 | [AliExpress](https://www.aliexpress.com/wholesale?SearchText=ESP32+devkit+v1+30+pin) |
| 4 | PCA9685 16-ch PWM driver | 1 | I2C servo driver | 5 | [AliExpress](https://www.aliexpress.com/wholesale?SearchText=PCA9685+16+channel+servo+driver) |
| 5 | MPU6050 IMU | 1 | heading/attitude (I2C) | 3 | [AliExpress](https://www.aliexpress.com/wholesale?SearchText=MPU6050+module+GY-521) |
| 6 | MS5837-30BA depth/pressure sensor | 1 | depth + leak-pressure (I2C); face epoxies into the lid port | 25 | [AliExpress](https://www.aliexpress.com/wholesale?SearchText=MS5837+30BA+pressure+sensor+module) |
| 7 | Leak probe (conductive pads) | 1 | GPIO34 safety cutoff (two bare wires + 1 MΩ pulldown works) | 2 | [AliExpress](https://www.aliexpress.com/wholesale?SearchText=water+leak+detection+sensor+module) |
| 8 | 2S LiPo 300–500 mAh | 1 | buffer; the 12 V tether supplies bulk power | 10 | [AliExpress](https://www.aliexpress.com/wholesale?SearchText=2S+7.4V+500mAh+lipo+battery) |
| 9 | Buck converter, **12 V → 5–6 V, ≥5 A** (servo bus) | 1 | robot-local; powers PCA9685 V+ and all 4 servos | 4 | [AliExpress](https://www.aliexpress.com/wholesale?SearchText=12V+to+5V+5A+buck+converter+module) |
| 9b | Buck converter, **12 V → 5 V, ~1 A** (MCU rail, into ESP32 VIN) | 1 | **separate** from the servo bus so stall spikes can't reset the MCU | 3 | [AliExpress](https://www.aliexpress.com/wholesale?SearchText=mini+360+buck+converter+module) |
| 9c | Bulk capacitor **1000–2200 µF, 16 V** + **4 A fuse** (servo bus) + small LED fuse | 1 | brownout fix from `power.py` (cap across the bus, fuse the bus + LED) | 3 | [AliExpress](https://www.aliexpress.com/wholesale?SearchText=2200uF+16V+capacitor+blade+fuse+holder) |

## Camera & light (the payload)
| # | Item | Qty | Notes | ~$ | Buy |
|---|---|-----|---|----|-----|
| C1 | Analog FPV mini camera, 700TVL+ CMOS, 5 V, PAL/NTSC | 1 | sits dry behind the nose window; composite out over a tether pair | 9 | [AliExpress](https://www.aliexpress.com/wholesale?SearchText=mini+FPV+camera+700TVL+CMOS+5V) |
| C2 | White LED module, 1–3 W (or 5730 LED board) | 1 | headlight behind the window, below the lens; black foam baffle between LED and lens kills internal glare | 3 | [AliExpress](https://www.aliexpress.com/wholesale?SearchText=3W+white+LED+module+5V) |
| C3 | Logic-level MOSFET board (AO3400 / IRLZ44 module) | 1 | ESP32 GPIO25 PWM dims the LED — never drive the LED from the pin | 2 | [AliExpress](https://www.aliexpress.com/wholesale?SearchText=mosfet+driver+module+trigger+switch+3.3V) |
| C4 | Acrylic / polycarbonate disc Ø30 × 3 mm (or cut from sheet) | 2 | nose window; epoxy-bond into the printed seat (`WINDOW_SEAT_D`); buy 2, scratch 1 | 4 | [AliExpress](https://www.aliexpress.com/wholesale?SearchText=clear+acrylic+disc+30mm+3mm) |
| C5 | USB video capture dongle (RCA composite → USB) | 1 | topside: turns the analog feed into a webcam on the laptop | 8 | [AliExpress](https://www.aliexpress.com/wholesale?SearchText=USB+video+capture+card+RCA+AV) |

## Tether & topside
| # | Item | Qty | Notes | ~$ | Buy |
|---|---|-----|---|----|-----|
| 10 | Cat5e cable, 3–5 m | 1 | 2 pairs power, 1 pair USB-serial, 1 pair composite video | 8 | [AliExpress](https://www.aliexpress.com/wholesale?SearchText=cat5e+ethernet+cable+5m+outdoor) |
| 11 | **Bench PSU 12 V / ≥3 A** | 1 | topside; feeds 12 V down the tether (bucked at the robot) | (have) | [AliExpress](https://www.aliexpress.com/wholesale?SearchText=12V+3A+power+supply+adapter) |
| 12 | USB-serial adapter (CP2102/CH340) | 1 | if not using the ESP32's own USB through the tether | 3 | [AliExpress](https://www.aliexpress.com/wholesale?SearchText=CP2102+USB+serial+adapter) |

## Sealing (head bay)
| # | Item | Qty | Notes | ~$ | Buy |
|---|---|-----|---|----|-----|
| 13 | O-ring, 2 mm cord, ~60 mm ID (metric assortment ok) | 2 | lid seal + a spare (see `ORING_*` params) | 3 | [AliExpress](https://www.aliexpress.com/wholesale?SearchText=nitrile+o-ring+assortment+2mm+cross+section) |
| 14 | Cable gland PG7 (or marine epoxy pot) | 1 | tether pass-through in the lid (`PENETRATOR_D` 10 mm) | 3 | [AliExpress](https://www.aliexpress.com/wholesale?SearchText=PG7+waterproof+cable+gland) |
| 15 | Marine / 2-part epoxy (30 min, not 5 min) | 1 | pots the servo-wire gland, the sensor port and bonds the window | 6 | [AliExpress](https://www.aliexpress.com/wholesale?SearchText=marine+epoxy+two+part+waterproof) |
| 16 | Silicone grease | 1 | O-ring lubrication | 4 | [AliExpress](https://www.aliexpress.com/wholesale?SearchText=silicone+grease+o-ring+waterproof) |

## Mechanical / printed
| # | Item | Qty | Notes | ~$ | Buy |
|---|---|-----|---|----|-----|
| 17 | PETG filament (PLA ok, freshwater) | ~150 g | prints all rigid `print_*.stl` | 5 | [AliExpress](https://www.aliexpress.com/wholesale?SearchText=PETG+filament+1.75mm+1kg) |
| 18 | TPU 95A filament (skin sleeve) | ~80 g | covers joint gaps (`skin.py`) | 10 | [AliExpress](https://www.aliexpress.com/wholesale?SearchText=TPU+95A+filament+1.75mm) |
| 19 | Joint pin, 3 mm **stainless** dowel ×25 mm (or M3 bolts) | 5 | `PIN_D`; do not print | 3 | [AliExpress](https://www.aliexpress.com/wholesale?SearchText=3mm+stainless+steel+dowel+pin+25mm) |
| 20 | Tail-fin foil sheet (or print it) | 1 | bolts to seg5 | 3 | [AliExpress](https://www.aliexpress.com/wholesale?SearchText=polycarbonate+sheet+1.5mm) |
| 21 | **Lead keel** ~200 g, low + forward | 1 | neutral + roll + trim (`stability.py`) | 5 | [AliExpress](https://www.aliexpress.com/wholesale?SearchText=lead+sheet+roll+fishing+weight) |
| 21b | **Buoyancy foam** ~59 cm³ closed-cell (2 discs cut to the bore, ~38+20 cm³) | 2 | seg2 + seg3 bays; combined centroid z~310 → floats level | 4 | [AliExpress](https://www.aliexpress.com/wholesale?SearchText=closed+cell+buoyancy+foam) |
| 21c | **Adjustable trim weight** ~15 g on a fore/aft slide | 1 | final LEVEL trim in water (sub-mm trim is touchy) | 2 | [AliExpress](https://www.aliexpress.com/wholesale?SearchText=m3+brass+weight) |
| 22 | Heat-set brass inserts, M2 / M3 | ~10 | threads in printed parts | 3 | [AliExpress](https://www.aliexpress.com/wholesale?SearchText=brass+heat+set+insert+M3+kit) |
| 23 | Stainless M2 / M3 screw assortment | 1 | lid, fins, hubs, horns | 4 | [AliExpress](https://www.aliexpress.com/wholesale?SearchText=stainless+M2+M3+screw+assortment+kit) |
| 24 | Pivot bushings 3 mm PTFE/brass (optional) | 5–10 | reduce joint wear | 4 | [AliExpress](https://www.aliexpress.com/wholesale?SearchText=3mm+ID+flanged+brass+bushing) |

**Rough total: ~$190** (excluding bench PSU). Biggest single items are the
depth sensor (#6, $25 — droppable if you skip depth-hold and drive the planes
open-loop) and the servos.

## Exact chosen parts (researched starting picks — confirm before buying)
These few items drive CAD fit / sealing / reliability. Below are **concrete,
currently-available picks** to start from (researched, not invented); confirm the
exact dimensions of what you actually receive, set `cad/params.py`, and re-export.
The CAD is currently dimensioned to the **Path-A servo** row.

| Critical part | Researched pick | Key dims | params it sets |
|---|---|---|---|
| **Servo ×4 — Path A (current CAD)** | **Tower Pro MG90S**-class metal-gear micro (~9–14 g, ~2.2 kg·cm), **potted** for submersion | ~22.8 × 12.2 × 22.7 mm body | `SERVO_BODY_*`=23/12.2/22.7, `SERVO_TORQUE_RATED`=0.20 |
| Servo ×4 — Path B (IP67, needs upsize) | [Savox **SW-0250MG**](https://www.savoxusa.com/products/savsw0250mg-waterproof-digital-micro-servo) — true IP67, no potting | 29.5 × 14.0 × 32.5 mm, **25 g**, 5 kg·cm | see note ↓ |
| O-ring (lid) | NBR 70A, **60 mm ID × 2.0 mm** cord (metric assortment) | ID 60, cord 2.0 | `ORING_CS`=2.0, `ORING_GROOVE_*` |
| Cable gland | **PG7** nylon waterproof gland (3–6.5 mm) | thread PG7, bore 10 mm | `PENETRATOR_D`=10 |
| Depth sensor | [Blue Robotics **Bar30**](https://bluerobotics.com/store/sensors-cameras/sensors/bar-depth-pressure-sensor/) (MS5837-30BA, I²C, ±2 mm, $85) — or a bare MS5837-30BA module (~$25) | I²C, 3.3–5.5 V | `SENSOR_PORT_*` |
| Window disc | Cast **acrylic Ø30 × 3 mm** disc (or cut from sheet) | Ø30, t3 | `WINDOW_SEAT_*` |

> **Servo path note (a real design finding, not hand-waving).** Genuinely
> submersible (IP67) servos are either *bulky* (20 kg-class units are 40×20×40 mm
> / 60 g — they don't fit a 70 mm body) or, like the Savox SW-0250MG, *fit but are
> 25 g — +44 g over the micro*. That extra mass needs ~+44 cm³ more buoyancy than
> the servo-crowded bays can hold (the narrow tail caps foam ≈ 79 cm³), so
> **Path B requires a longer hull or an external foam collar**. **Path A**
> (a cheap metal-gear micro you pot yourself) is what the current balanced CAD
> uses — neutral, roll-stable, ~2° trim (`stability.py`). Pick A for a drop-in
> build; pick B only if you also upsize the body and re-run `stability.py`.

## Printed parts manifest
`print_head.stl` (now with the nose-window seat), `print_lid.stl` (carries
the joint-1 tongue; 3 penetrations: tether, wire gland, sensor port),
`print_seg1.stl` … `print_seg5.stl` (band anchor posts + drain holes are
printed in), `print_tailfin.stl`, `print_dive_plane.stl` (×2, mirror one),
`print_dive_crank.stl`, `print_skin.stl` (TPU), `print_test_rig.stl`.
`print_pin.stl` (×5) and `print_dive_shaft.stl` are **dry-fit templates
only** — use the stainless pins (#19) and 4 mm rod (#2b) in water.

**Stability / ballast hardware** (`cad/ballast.py`): `print_keel_strap.stl`,
`print_trim_rail.stl`, `print_trim_carrier.stl`, `print_foam_retainer.stl`.
**Passive-tail flexures** (`cad/tail_flexure.py`, print in TPU):
`print_flexure_2p8.stl`, `_3p4.stl`, `_4p0.stl` — print all three, bench-pick
by `f_n` (build_guide §12).

**Test coupons** (`cad/test_coupons.py` — print + test BEFORE the full body):
`coupon_servo.stl` (servo + mount fit), `coupon_potting.stl` (wire-gland potting
cup), `coupon_oring_bore.stl` + `coupon_oring_plug.stl` (radial-seal fit). Pass
criteria in build_guide §12.

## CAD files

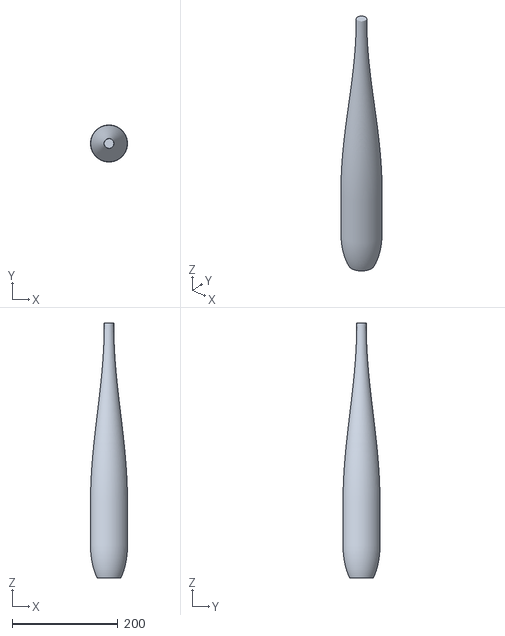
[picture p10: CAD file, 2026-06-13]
cfd/constant/triSurface/cfd_hull.stl
70.0 x 70.0 x 482.0

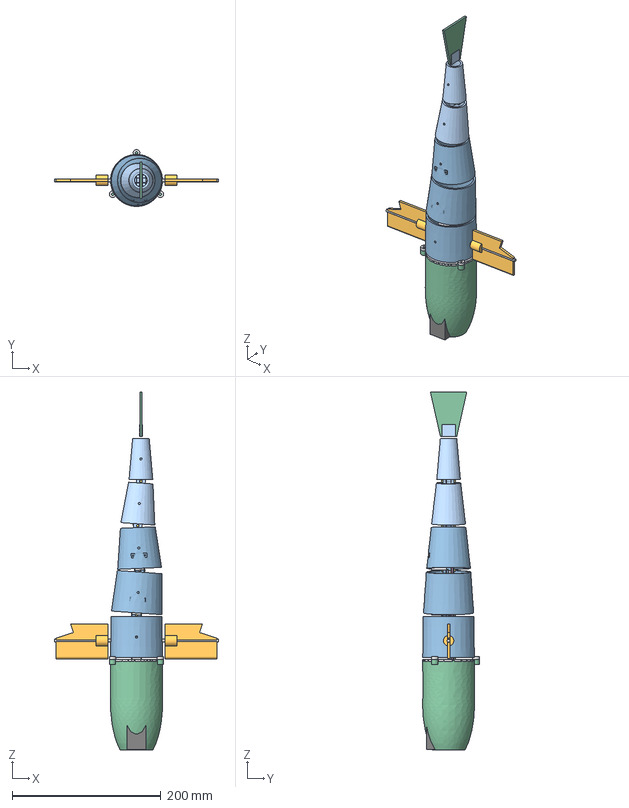
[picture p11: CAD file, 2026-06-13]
output/eel_swim.step
221.0 x 76.5 x 481.6 mm
head
lid
dive_plane_R
dive_plane_L
dive_shaft
seg1
seg1_servo
seg1_horn
seg1_pin
seg2
seg2_servo
seg2_horn
seg2_pin
seg3
seg3_servo
seg3_horn
seg3_pin
seg4
seg4_pin
seg5
seg5_pin
tailfin
tray
battery
esp32
pca9685
mpu6050
buck
ms5837
camera
led
keel
dive_servo

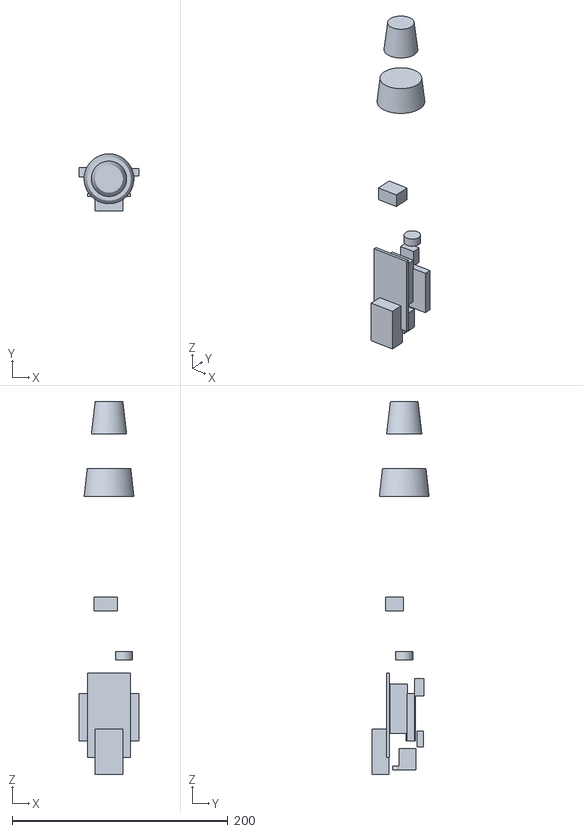
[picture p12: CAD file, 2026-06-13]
output/internals_layout.stl
56.0 x 53.1 x 346.0

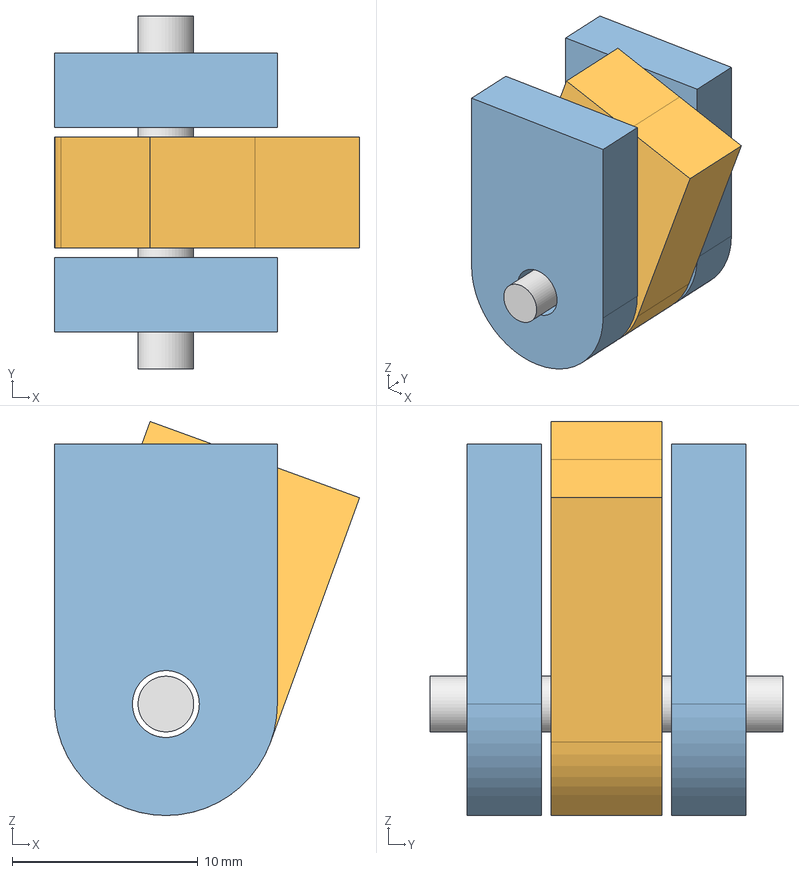
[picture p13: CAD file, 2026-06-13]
output/joint_demo.step
16.4 x 19.0 x 21.2 mm
clevis
tongue
pin

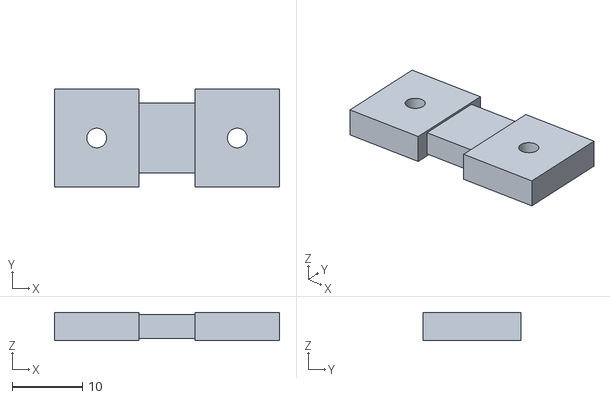
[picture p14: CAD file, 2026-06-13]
output/print_flexure_3p4.stl
32.0 x 14.0 x 4.00

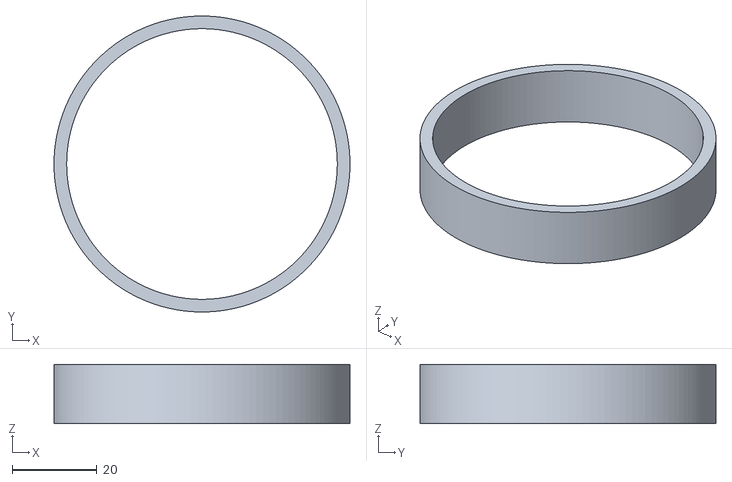
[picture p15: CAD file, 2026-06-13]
output/coupon_oring_bore.stl
70.0 x 70.0 x 14.0

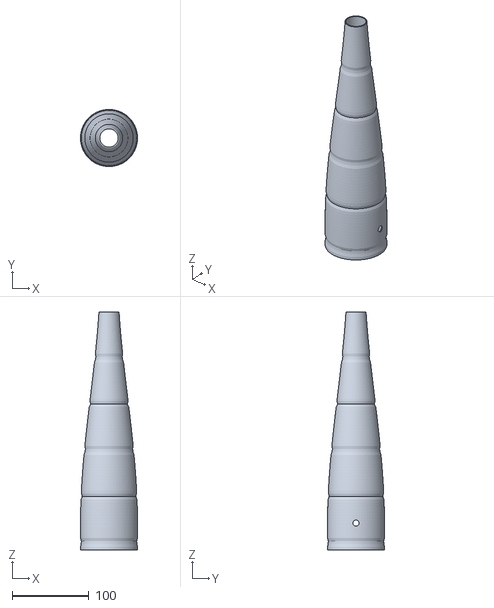
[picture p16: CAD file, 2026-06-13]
output/print_skin.stl
74.4 x 74.4 x 310.0

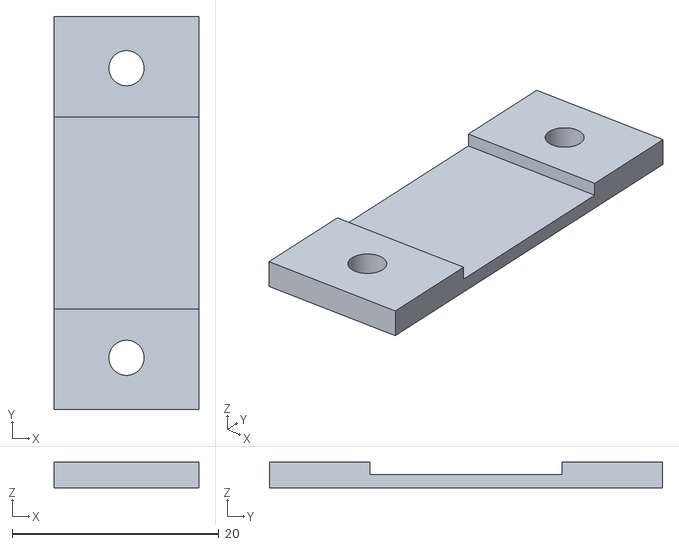
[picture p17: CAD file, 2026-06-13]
output/print_keel_strap.stl
14.0 x 38.0 x 2.50

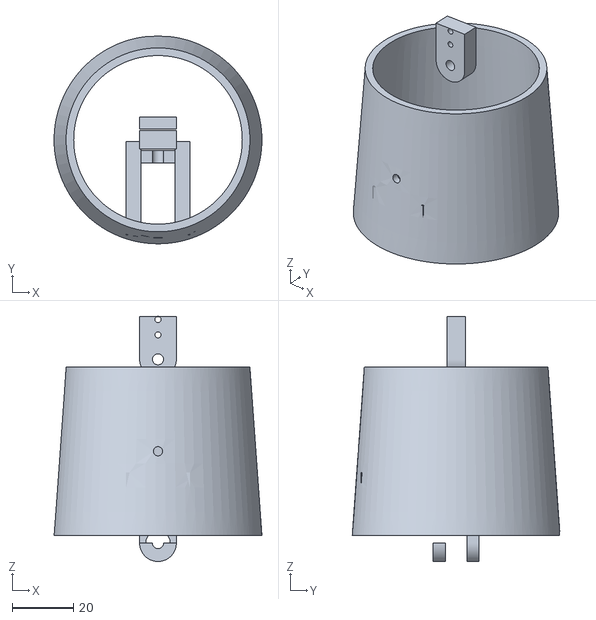
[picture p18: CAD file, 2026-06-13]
output/print_seg2.stl
67.9 x 67.8 x 80.0

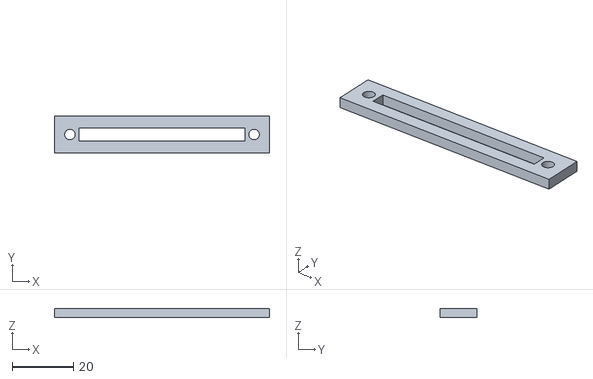
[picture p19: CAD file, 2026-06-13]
output/print_trim_rail.stl
70.0 x 12.0 x 3.00

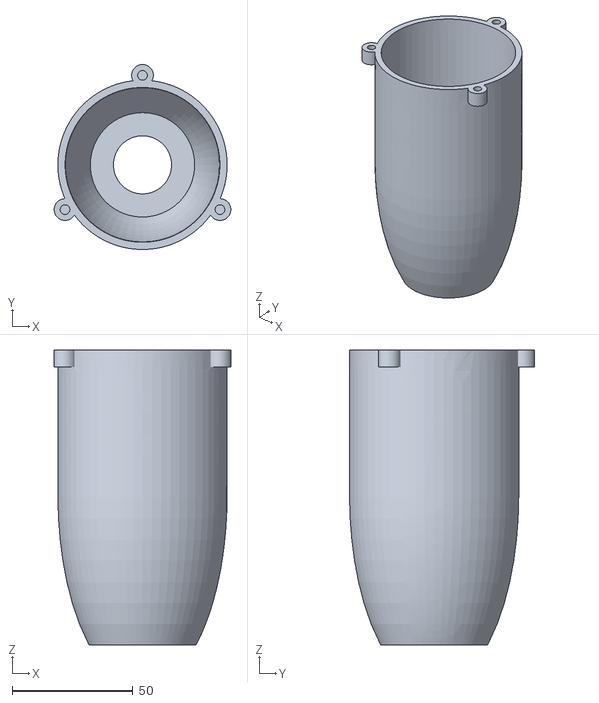
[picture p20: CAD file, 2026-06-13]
output/print_head.stl
73.1 x 76.5 x 122.0

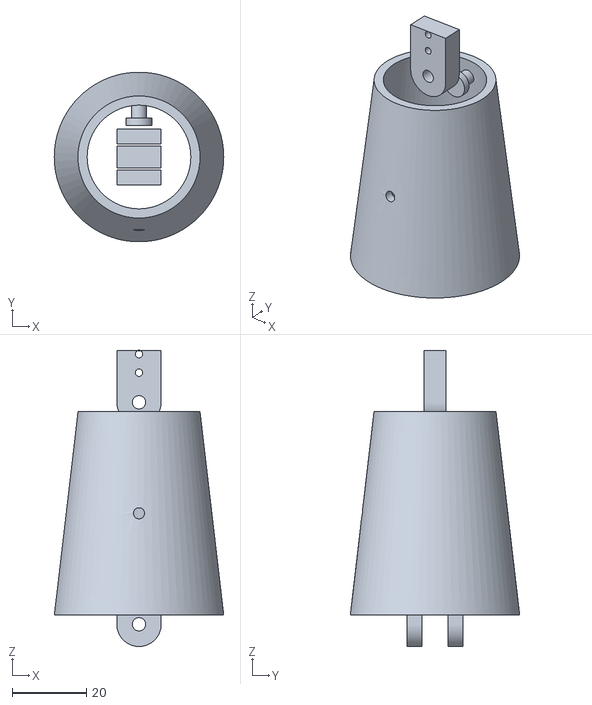
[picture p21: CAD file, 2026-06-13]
output/print_seg4.stl
45.8 x 45.8 x 80.0

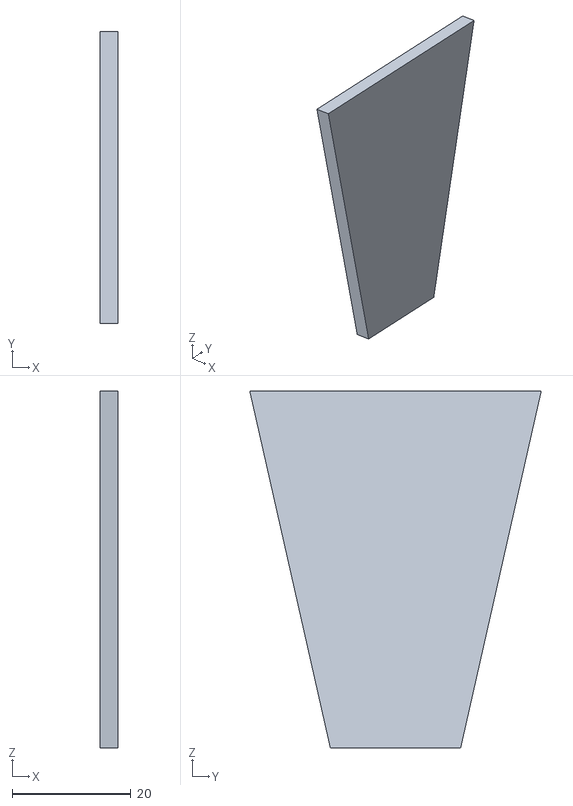
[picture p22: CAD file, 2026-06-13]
output/print_tailfin.stl
3.00 x 49.0 x 60.0

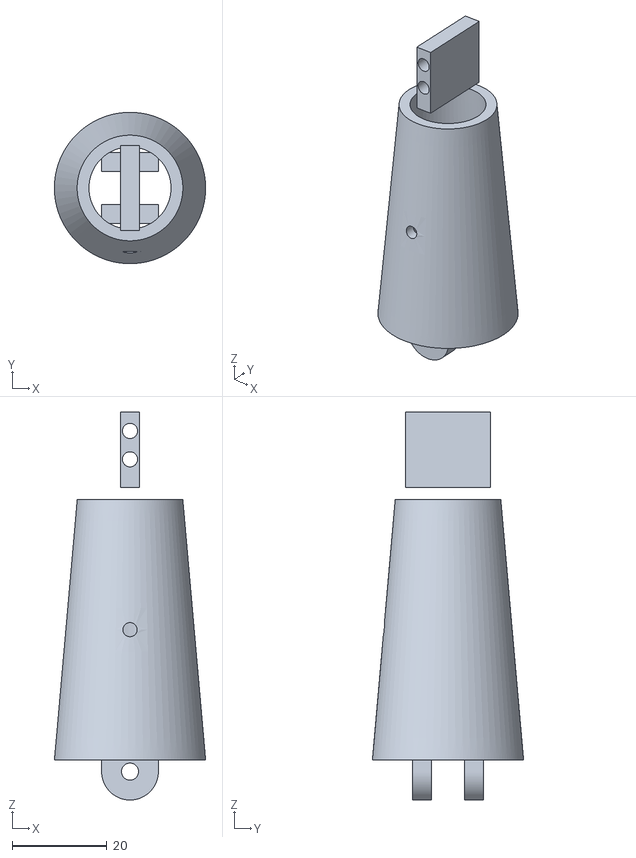
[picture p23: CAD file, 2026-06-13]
output/test_seg5.stl
32.0 x 32.0 x 82.0

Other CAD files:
output/eel_straight.step
output/cfd_hull.step
output/print_flexure_4p0.stl
output/coupon_oring_plug.stl
output/coupon_potting.stl
output/coupon_servo.stl
output/joint_demo.stl
output/lid.stl
output/print_dive_crank.stl
output/print_dive_plane.stl
output/print_dive_shaft.stl
output/print_flexure_2p8.stl
output/print_foam_retainer.stl
output/print_lid.stl
output/print_pin.stl
output/print_seg1.stl
output/print_seg3.stl
output/print_test_rig.stl
output/print_trim_carrier.stl
output/test_seg1.stl

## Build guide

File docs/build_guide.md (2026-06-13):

# Build Guide — Bio-Inspired Eel Robot

The step-by-step to go from the files to a swimming robot. Read
[manufacturing.md](manufacturing.md) (materials/print settings) and
[BOM.md](BOM.md) (parts) first. Every number here is produced by the analysis
scripts — re-run them after any change.

> Status: this is a **design-complete preliminary package — a verified digital
> prototype**, not a finished, physically-proven product. Geometry, stability,
> structure, power and control are analysed and self-consistent and the whole
> pipeline regenerates (`verify_all.py` → 28/28). What it is **NOT**: wet-tested,
> CFD-solved, or pinned to exact purchased SKUs. Performance numbers are
> **predicted**; depth/heading hold are **experimental** (bench-untested). Treat
> the first build as the validation — the checklist and the §12 test coupons say
> exactly what's done vs what you must confirm.

---

## 0. Pre-flight (decide + buy)
- Pick your **servo** → set `SERVO_BODY_*`, `SERVO_TORQUE_RATED` in `params.py`,
  re-export. Buy **4 identical** waterproof micro servos (3 joints + 1 dive).
- Pick **fresh vs salt** → 304 vs 316 stainless, NBR vs EPDM O-rings.
- Confirm **printer build volume** vs the longest part (head ~140 mm).

## 1. Print (PETG unless noted)
`print_head`, `print_lid`, `print_seg1..5`, `print_tailfin`, `print_dive_plane`
(×2, mirror one), `print_test_rig`; **`print_skin` in TPU**. Orientation +
settings in [manufacturing.md](manufacturing.md). **Do NOT print** the pins or
shafts — buy stainless rod. Print **seg1 + the joint demo first** and check the
pin-bore + servo-pocket fit before committing to all 5.

## 2. Joints
- Every joint = **clevis + tongue + 3 mm stainless pin** (the hinge).
- **Driven (joints 1–3):** servo drops into the seg pocket, **flanges screw to
  the two bosses**, shaft up; **horn bolts to the next segment's tongue**.
- **Passive (joints 4–5):** no servo. Fit the **compliant element** — print the
  inter-segment link in **TPU**, thickness from `tail_stiffness.py`
  (**~4.0 mm at joint 4, ~2.8 mm at joint 5**), *or* loop a rubber band over the
  printed posts at the matching rate. **Tune later** (§7).
- **Tail fin:** 2 M3 screws into seg5 (solid, no hinge).
- Segments sit with a **5 mm gap** (`SEGMENT_GAP`) so they don't collide when
  bending — that's intentional; the skin covers it.

## 3. Dive planes
One rod through both fins; the **dive servo (aft of the joint-1 servo, ~z180)**
turns it via a **crank + link**; the far rod end rides in a **bushing** in the
hull. Both fins move together. `+` plane angle = dive (leading edge down).
Build the crank + link as a **parallelogram** (crank arm = servo-horn arm, link
length = the rod-to-servo offset, arms parallel at neutral) → exact **1:1**
servo-to-fin angle, no dead-point. Set the rod at **~0.28 chord** (near the
centre of pressure) so the hinge moment stays tiny. `dive_linkage.py` verifies
1:1 over ±25° and a **×29 servo torque margin** at cruise.

## 4. Head bay + camera
- Bond the **acrylic window** into the nose seat (epoxy). **Camera + LED mount
  behind it, inside the dry bay** — they stay dry, look through the window.
- Electronics tray slides in from the rear lid: **battery low+centre**, ESP32 +
  PCA9685 on the sides, IMU + buck up top, **MS5837 face epoxied into the lid
  sensor port** (gel side to water).
- Three lid bores: **O-ring lid**, **potted wire gland** (servo/leak wires),
  **sensor port**. Penetrator/gland potted with marine epoxy.

## 5. Stability hardware  (from `stability.py` — this is NOT optional)
The bare design floats **nose-up and rolls easily**. Fix:
- **Buoyancy foam ~59 cm³** (closed-cell) as **two discs cut to the bore** —
  ~38 cm³ in the seg2 bay + ~20 cm³ in the seg3 bay — straddling the joint so
  their combined centroid lands at **z~310** (rear-mid) to trim level. Each disc
  slides into its bay and is **glued/captured** so it can't float out.
- **Lead keel ~200 g**, **low + forward (z~40, belly)** — sets roll + trim.
- **Adjustable trim weight ~15 g** on a fore/aft slide for final level trim.
Result (computed): **floats level (CG=CB), roll margin ~8 mm, neutral.** Exact
pitch is touchy near neutral → set it in the water with the trim weight.

> Note — the foam works *because* the body floods. The skin is a **permeable
> fairing**, not a watertight bag: water passes through the drain holes and sits
> on both sides of it. Closed-cell foam is **self-sealing at the bubble level**
> (each cell traps its own gas), so it displaces that flood water and lifts
> ~55 g regardless of the skin. Use genuine **closed-cell** marine foam (not
> open-cell sponge — it would soak through and lift nothing), and **glue/capture
> it** in its bay so it can't float out.

## 6. Electronics + power  (from `power.py`)
- Size the supply for the **~4 A peak** (all servos stall), not the 6 W average.
- **ESP32 on its own buck (5 V → VIN)**, NOT the servo rail (or stall spikes
  reset it). One topology everywhere: **12 V tether → two robot-local bucks**
  (5–6 V servo bus + 5 V MCU). See [wiring_pinout.md](wiring_pinout.md).
- **1000–2200 µF bulk cap** across the servo bus; **~4 A fuse** on the bus,
  separate fuse for the LED.
- **Tether: run 12 V, buck to 5–6 V AT THE ROBOT** (5–6 V down thin wire drops
  >1 V at peak). Use AWG18–20 power pairs. Wire per [wiring.drawio](wiring.drawio).

## 7. Firmware  (`firmware/eel_gait.ino`)
- Libraries: `Adafruit_PWMServoDriver`, `Wire`, **`MS5837` (BlueRobotics)**.
  Build with the **ESP32 Arduino core 2.0.x** (the LED PWM uses
  `ledcSetup`/`ledcAttachPin`; 3.x changed that API). Servos on PCA9685 ch0–2
  (joints) + ch5 (dive). IMU (MPU6050) on I2C; leak GPIO34; LED GPIO25.
- On boot it **calibrates the gyro zero — hold the robot still ~1 s** and prints
  `MS5837 OK` / `FAIL`.
- Serial @115200: `S`peed, `H` manual bias, **`Y`<deg> hold heading (IMU)**,
  `M`anual, `D`<depth> hold depth, `L`evel, `W`<0–1> light, `X` e-stop.
- **Depth-hold + heading-hold are CLOSED-LOOP but BENCH-UNTESTED — treat as
  experimental.** Depth-hold is *refused* unless the MS5837 actually reads (no
  acting on a fake depth); heading is gyro-only and **drifts** (add a
  magnetometer for absolute heading). Tune the PID gains on the bench.

## 8. Tune the passive tail (bench)
Assemble the tail, **pluck it, time 10 swings → natural frequency**. Add/remove
TPU thickness (or band tension) until **f_n ≈ 2.5 Hz** (`tail_stiffness.py`).
Too stiff = won't undulate; too soft = flops and lags.

## 9. Waterproof — DRY TEST FIRST (do not skip)
1. Print + seal the head bay; grease + fit the O-ring lid.
2. **Submerge the EMPTY bay, weighted, 10 min — check for ingress.** Fix before
   any electronics go in.
3. Pot the penetrator/gland + window; re-test.
4. Waterproof the servos (buy waterproof or pot); conformal-coat the PCB.
5. Drill the segment **drain holes** open; final **powered leak test, leak
   sensor armed**.

## 10. Ballast & trim in water
1. Fit foam + keel (§5). In a tub, confirm **roughly neutral** (sinks slowly).
2. Slide the **trim weight** until it floats **level** (no pitch).
3. Aim **slightly positive (+15–20 g)** so it surfaces if powered off.

## 11. Test order
Bench (on the test rig): servo sweep in phase → heading-hold response →
depth-plane response. Then **tethered pool**: cruise, measure speed vs the
Strouhal target, turn (heading-hold), dive/climb. Log + compare to the reports
in `output/`.

## 12. Test coupons & acceptance (pass/fail — do these before the full build)
The coupons are **real printable STLs** (`cad/test_coupons.py` → `coupon_*.stl`,
`cad/ballast.py`, `cad/tail_flexure.py`) — print + test each; every row has a
**go/no-go** so you're not guessing. Don't print the whole body until the fit +
seal coupons pass.

| Test | Method | PASS threshold |
|---|---|---|
| Servo-pocket fit | print **`coupon_servo.stl`**; drop your servo in | servo seats, both mount screws bite, horn clears, no bind |
| O-ring radial fit | print **`coupon_oring_bore.stl` + `_plug.stl`**, fit with the greased O-ring | smooth slide, even squeeze, no roll-out |
| Bay seal | empty bay, lid + window in, weighted, submerged 10 min | **zero ingress** (dry tissue inside / no bubble stream) |
| Potted wire bundle | pot a bundle in **`coupon_potting.stl`**, submerge + flex 30–60 min | **zero ingress / no wicking** under the jacket |
| Wet servo soak | submerge the (potted/WP) servo, drive it 30 min | runs, no stall/ingress, insulation dry |
| Leak sensor | drip water across the probe at the bay low point | latched e-stop **< 2 s**; **no** false trip when dry |
| Depth sensor | `MS5837 OK` on boot; dunk in a measured water column | reads depth within **±3 cm** of true |
| Tail stiffness | print `print_flexure_2p8/3p4/4p0.stl`, fit each, pluck, time 10 swings | **f_n = 2.5 ± 0.5 Hz** (`tail_stiffness.py`) — keep the variant that passes |
| Power brownout | stall all 4 servos at once on the real supply | ESP32 **does not reset**; fuse holds; bus cap fitted |
| Dry gait | run the gait on the rig | 3 servos sweep in correct travelling-wave phase, no brownout |
| **Dry driven-tail** | drive the front 3 joints dry, watch the passive tail | tail **follows in-phase**, amplitude **grows** toward the tip (not floppy, not rigid) — do before any pool test |

---

## Build-readiness checklist
Legend: ✅ **designed/analysed** (reproducible in software — *not* physically
tested) · ⚠️ **placeholder/experimental** (needs your input or a bench test) ·
⬜ **physical** (only the first build can close it). Every ✅ performance number
is **predicted until wet-tested** — see §11.

| Item | State |
|---|---|
| Geometry, joints, mounts, fits | ✅ parametric, exports clean |
| Drag / buoyancy / gait / self-propulsion | ✅ first-order **predicted** (Cd assumed, **no CFD solve**) |
| **CG/CB stability + trim** | ✅ analysed + fixed (foam+keel+trim weight) |
| Structure (pressure / pin / O-ring) | ✅ analytic margins to ~84 m (no lid-clamp/penetrator/fatigue FEA) |
| **Passive-tail stiffness** | ✅ 3 TPU flexure variants generated (`tail_flexure.py`) — bench-pick the passing one (§12) |
| **Dive-plane linkage** | ✅ parallelogram 1:1, ×29 holding-torque margin (`dive_linkage.py`) |
| **Power: peak / brownout / tether drop** | ✅ analysed + mitigations specified |
| **Wiring / pin map** | ✅ pin-level table ([wiring_pinout.md](wiring_pinout.md)) matches firmware |
| **Lid retention** | ✅ radial O-ring (no clamp force) + joint-1 pin + 3 M3 bolt ears (`head_bay.py`) |
| Free-flood venting | ✅ drain/vent holes in CAD |
| **Whole pipeline reproducible** | ✅ `python verify_all.py` → 28/28 pass |
| Servo + exact part SKUs / dims | ⚠️ **placeholder** until you choose parts — then re-export |
| **Depth-hold / heading-hold** | ⚠️ **experimental** — closed-loop, bench-untested (depth needs MS5837 read; heading drifts, gyro-only) |
| Wet-side wiring / potting / leak-sensor proof | ⚠️ strategy specified — needs test coupons (§12) |
| Anything physical (print/seal/swim) | ⬜ to be validated on the first build |

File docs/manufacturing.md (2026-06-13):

# Manufacturing & Materials Specification — Eel Robot

The single place that answers: **what is each part made of, how is it made,
what hardware holds it together, and how is it sealed.** Numbers trace to
`cad/params.py`; change them there and re-export. Tier: desk/pool prototype.

---

## 1. Material per part (metal vs plastic)

| Part | Material | Process | Why |
|---|---|---|-----|
| Head bay + lid | **PETG** (or tough resin) | FDM print (or SLA) | watertight, low water-absorption, impact-tough; resin gives the best sealing surface |
| Body segments seg1–5 | **PETG** (PLA ok for short freshwater) | FDM print | complex shape, light, free-flooding so not pressure-critical |
| Dive planes, tail fin | PETG | FDM print | thin foils, low load |
| Skin sleeve | **TPU 95A** (or cast silicone) | FDM print / mould | must flex over the joints |
| Test rig | PLA/PETG | FDM print | dry bench tool |
| **Joint pins** (×5) | **Stainless steel** 3 mm dowel (or A2/A4 M3) | bought | bearing/wear + corrosion — *do not print* |
| **Dive shaft** | **Stainless steel** 4 mm rod | bought | torque + wear |
| **Fasteners** | **Stainless** M2 / M3 screws | bought | thread strength, corrosion |
| **Thread inserts** | **Brass** heat-set M2 / M3 | bought | printed plastic can't hold threads |
| Pivot bushings (optional) | Brass / PTFE, 3 mm ID flanged | bought | reduce pivot wear (printed bore works for proto) |
| Ballast | **Lead or steel** shot/sheet | bought | density — needs metal |
| **Nose window** | **Acrylic / polycarbonate** disc Ø30 × 3 mm | bought | optically clear for the camera — printed plastic is not |

**Rule of thumb:** *fairings & body = printed plastic; anything that bears a
load, threads, wears, or must be dense = metal (stainless if you'll go salt
water; brass for inserts; lead/steel for ballast).*

---

## 2. 3-D print settings

| Setting | Value | Note |
|---|---|---|
| Layer height | 0.16–0.20 mm | 0.16 on head bay for seal finish |
| Walls / perimeters | **≥ 4** (6 on head bay) | water tightness comes from walls, not infill |
| Infill | 30–40 % body segments; near-solid head bay & thin parts | |
| Material | PETG ~245 °C / bed 80 °C; TPU ~225 °C slow | dry filament — PETG/TPU absorb moisture |
| Skin (TPU) | 0.8–1.2 mm wall, 100 % flow, 15–20 mm/s | print slow for layer bonding |

**Print orientation**
- **Head bay:** flat window face **down** (nose down), open rear **up** → clean bore, flat seat, no seam across the seal.
- **Segments:** body axis **vertical (Z up)** → round cross-section, minimal supports; clevis prongs may need light support.
- **Dive planes / tail fin:** flat on the bed.
- **Pins / shaft:** **do not print — use the metal rod.**

**Supports:** servo pockets, clevis undersides, penetrator bore, and the small
rubber-band anchor posts that hang from the shell ceiling around the passive
joints (seg3 rear, seg4, seg5). **Drain holes** (Ø3 mm, `DRAIN_HOLE_D`) are
printed into the low point of each free-flooding segment so water fills/drains.

---

## 3. Tolerances & fits (printed)

| Feature | Param | Value | Action |
|---|---|---|---|
| Pin bore clearance | `PIN_CLEAR` | 0.30 mm over pin | ream/drill bore to final Ø after print |
| Servo pocket clearance | `SERVO_POCKET_CLEAR` | 0.6 mm | tune to your exact servo |
| Lid slip fit | — | 0.2 mm | sand for a smooth O-ring entry |
| Clevis gap | `CLEVIS_GAP` | tongue + 1.0 mm | 0.5 mm/side |

FDM holes print **undersize** — drill `PIN_D` (3 mm) and shaft (4 mm) bores to
size with a bit. Print one segment + the joint demo FIRST and adjust these.

---

## 4. Sealing specification

Only the **head bay is sealed**; segments are **free-flooding** (drain holes
are printed in). Six sealed interfaces:

| Interface | Seal | Spec (from params) |
|---|---|---|
| Lid → bay bore | radial O-ring | bay bore Ø **64 mm** (= 2·(R_MAX−BAY_WALL)). Use **O-ring ≈ 60 mm ID × 2 mm CS** (NBR/Buna). ONE groove, **on the lid plug**: `ORING_GROOVE_W` 2.4 × `ORING_GROOVE_D` 1.5 mm (the bay bore is plain). Target squeeze 15–25 % — verify on the printed groove. |
| Tether → lid | gland | `PENETRATOR_D` 10 mm bore, offset **+12 mm (up)**: PG7 cable gland **or** pot with marine epoxy |
| Servo / leak wires → lid | epoxy pot | `WIRE_GLAND_D` 10 mm bore, offset **−12 mm (down)**: feed all 4 servo leads + leak probe through, then **pot solid with marine epoxy** (fill the bore, wires fanned so epoxy wets every jacket) |
| MS5837 → lid | epoxy pot | `SENSOR_PORT_D` 8 mm bore at **x = +14 mm**: sensor face (gel side) looks OUT through the port into the flooded seg1; epoxy the rim from the dry side. Do NOT get epoxy on the gel. |
| Window → nose | epoxy bond | acrylic disc Ø30 × 3 into the `WINDOW_SEAT_D` 31 mm recess: thin bead of epoxy on the 3.5 mm lip, press flush, wipe squeeze-out off the aperture before it cures |
| Servo case/shaft | waterproofing | buy **waterproof servos**, or pot the case seam + shaft with marine grease/epoxy |

Aids: **silicone grease** on every O-ring; **conformal coat** the PCB as a
backup; arm the **leak sensor** before submerging.

---

## 5. Fastener & hardware schedule

| Use | Item | Qty | Detail (pilot / insert / length) |
|---|---|---|---|
| Joint pivots | 3 mm SS dowel (or M3×~25 + nylock) | 5 | Ø3.0 pin bore; double-shear, big SF (`structures.py`) |
| Dive-plane shaft | 4 mm SS rod, ~225 mm | 1 | rides in 2 hull bushings; grub-screwed to the crank |
| Servo horns | M2 self-tap (servo-supplied) | 4 | into the horn; pattern set by the chosen servo |
| **Lid clamp** | **M3×10 SS cap + brass heat-set insert** | **3** | ears at PCR 37 mm; insert **Ø4.0×6** in the head ear, **Ø3.4** clearance in the lid tab (`head_bay.py`) |
| Servo mounts | M2.5 self-tap into bosses | 8 | 2 per driven servo + dive; pilot Ø2.1 in `body.servo_mount` |
| Tail fin → seg5 | M3×10 SS + insert | 2 | insert Ø4.0×6 |
| Dive-plane hubs → shaft | M3 grub/set screw | 2 | onto a shaft flat |
| Heat-set inserts | brass M3, Ø4.0 OD × ~5–6 long | ~7 | lid ears (3) + tail (2) + spares |
| Pivot bushings (opt.) | 3 mm ID PTFE/brass | 5–10 | longer joint life |

**Ballast retention** (the stability fix is *not* optional — install it
repeatably): the **2 foam discs** are closed-cell, sized to the seg2/seg3 bore
(`params.FOAM_PLUGS`) — **friction-fit + a dab of silicone** so they can't float
out (they're positively buoyant). The **lead keel** epoxies into the forward
belly with a **2× M3 strap** as backup. The **trim weight** (~15 g) rides on a
**slotted rail / Velcro** so you can slide it fore/aft and set level in the water.

---

## 6. Waterproofing procedure (do in this order)

1. Print head bay + lid (PETG/resin), ream the bore smooth, sand the window
   seat flat.
2. **Bond the nose window:** thin epoxy bead on the seat lip, press the
   acrylic disc in flush, wipe the aperture clean. Cure fully.
3. Fit O-ring to the lid groove, grease it, insert lid — check even squeeze.
4. **Dry leak test the EMPTY bay first** (window in, lid bores taped/plugged):
   weight it, submerge 10 min, look for ingress (tissue paper inside /
   bubbles out). Fix before adding electronics.
5. Fit the tether gland (+12 mm bore); feed servo + leak wires through the
   −12 mm bore and **pot it solid with epoxy**; epoxy the MS5837 face into
   the +14 mm port (gel side out, no epoxy on the gel). Cure; re-test.
6. Waterproof servos (buy waterproof, or pot seam + shaft); conformal-coat PCB.
7. Assemble; **final powered leak test** with the leak sensor armed — camera
   picture up, light on, servos sweeping, 10 min submerged.
8. Ballast/trim to neutral (~150 g, slightly positive for fail-safe surfacing).

---

## 7. Internal layout — where each thing goes

Modeled in `cad/internals.py`; see it live in `output/eel_design.html` (tick
**internals** → body turns translucent, or click any electronics part).

- **Head dry bay** holds the electronics on a **tray that slides in from the
  rear lid**: **2S LiPo at the bottom-centre** (heaviest → keep low and a touch
  forward of the centre of buoyancy for pitch stability), **ESP32 + PCA9685**
  on the sides, **MPU6050 + buck** on top, **MS5837 on the lid end-cap** with
  its face epoxied into the lid's sensor port (reads ambient pressure through
  the flooded seg1 behind).
- **Camera + LED** sit at the very front, looking out the nose window: lens on
  the axis, LED below it, a **black foam baffle between LED and lens** so the
  light doesn't flare the image off the acrylic. Velcro or hot-glue both to a
  small printed shelf / the bay floor.
- **Dive servo (the 4th)** sits in the **front body just behind the head**,
  axis **across** the body, coupled to the dive-plane shaft — a **waterproof
  servo in the free-flooding section** (no extra shaft seal needed).
- **Joint servos (×3)** — one inside each DRIVEN segment (seg1–seg3), at the
  segment's front pivot. Joints 4–5 are the passive compliant tail: no servo —
  a printed **TPU flexure is primary** (`tail_flexure.py`, 3 variants; bench-pick
  by f_n), with **rubber bands over the anchor posts as the fallback**.
- Battery placement is the main **trim/CG** lever: shift it fore/aft to set the
  pitch attitude, low to keep the centre of mass under the centre of buoyancy.

## 8. What is NOT specified (decide when you buy)

- **Exact servo** → sets `SERVO_BODY_*` + `SERVO_TORQUE_RATED` + horn pattern in
  `params.py`. **Reference design point:** a **metal-gear ~9–20 g micro servo,
  ≥2.5 kg·cm @ 6 V** (torque is not the limiter — `structures.py`/`dive_linkage.py`
  show ~20–40× margin — *fit and waterproofing* are). After you buy, measure the
  body L×W×H + horn and set `params.py`, then print the servo-pocket fit coupon.
  - **Waterproofing reality (important):** most "waterproof" hobby servos are
    *splash/IP-rated, not rated for continuous submersion*. For a free-flooding
    body either buy a genuinely submersible servo **or pot the case seam + shaft
    exit** yourself, and run the wet-servo soak coupon (build_guide.md §12) before
    trusting it. This is the single biggest reliability risk in the build.
- Resin vs PETG for the bay (resin seals better, PETG is tougher).
- Whether you need bushings (proto: skip; longer life: add).
- Salt vs fresh water → drives stainless **316** vs 304 and NBR vs EPDM O-rings.

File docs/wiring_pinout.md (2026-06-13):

# Wiring & Pinout — Eel Robot

Pin-level companion to the block diagram in [wiring.drawio](wiring.drawio). Every
pin here matches a constant in [firmware/eel_gait.ino](../firmware/eel_gait.ino) —
if you change a pin, change it in both places.

Controller: **ESP32 dev board**. Servos are driven by a **PCA9685** over I²C (the
ESP32 does not PWM the servos directly). All I²C devices share one bus.

## ESP32 pin map
| ESP32 pin | Net | Goes to | Dir | Notes |
|---|---|---|---|---|
| GPIO21 | `SDA` | PCA9685, MPU6050, MS5837 | I/O | shared I²C data; 4.7 kΩ pull-up to 3V3 |
| GPIO22 | `SCL` | PCA9685, MPU6050, MS5837 | I/O | shared I²C clock; 4.7 kΩ pull-up to 3V3 |
| GPIO34 | `PIN_LEAK` | leak probe | **in** | input-only pin → needs an **external 100 kΩ pull-down** (HIGH = water) |
| GPIO25 | `PIN_LED` | LED MOSFET gate | out | PWM-dimmed headlight; gate a logic-level MOSFET, **never drive the LED off the pin** |
| TX0/RX0 | `UART0` | USB-serial → topside | I/O | console @ **115200**; the tether's data pair |
| VIN (5V) | `5V_MCU` | buck B output | pwr | ESP32's own 5 V feed → onboard 3V3 LDO |
| 3V3 | `3V3` | I²C devices' logic | pwr | logic rail for PCA9685 VCC, IMU, depth sensor |
| GND | `GND` | common | pwr | **single common ground** (servo + logic grounds tied) |

## PCA9685 servo channels
| Channel | Servo | Constant | Travel |
|---|---|---|---|
| CH0 | Joint 1 (seg1) | `JOINT_Z_MM[0]=140` | ±28° mech, ±7° cruise |
| CH1 | Joint 2 (seg2) | `JOINT_Z_MM[1]=200` | ±28° |
| CH2 | Joint 3 (seg3) | `JOINT_Z_MM[2]=260` | ±28° |
| CH5 | Dive planes | `DIVE_CH=5` | ±25° (`DIVE_MAX_DEG`) |
| CH3, CH4 | — | spare | — |

PCA9685: `VCC`=3V3 (logic), `V+`=**servo bus 5–6 V**, frame `PCA_FREQ_HZ=50`,
addr `0x40`. Servo pulse `SERVO_MIN_US..MAX_US = 1000..2000 µs`, centre 1500 µs.

## I²C device addresses
| Device | Addr | Role |
|---|---|---|
| PCA9685 | `0x40` | 16-ch servo PWM |
| MPU6050 | `0x68` (`MPU_ADDR`) | IMU — gyro-Z for heading hold |
| MS5837 | `0x76` | depth / pressure for depth hold |

## Power rails
Tether carries **12 V** (not 5–6 V — see [power.py](../analysis/power.py): thin
wire drops >1 V at peak). Both bucks live **at the robot**, in the dry bay.

| Rail | Source | Feeds | Protection |
|---|---|---|---|
| 12 V tether | topside PSU | buck A, buck B | inline fuse topside |
| 5.5 V servo bus | buck A (12→5.5 V, ≥5 A) | PCA9685 `V+`, all 4 servos, LED | **~4 A fuse** + **1000–2200 µF** bulk cap across the bus |
| 5 V MCU | buck B (12→5 V, ~1 A) | ESP32 `VIN` | **separate** from servo bus (stall spikes must not reset the MCU) |
| 3V3 | ESP32 onboard LDO | I²C logic | — |
| LED | servo bus via MOSFET | headlight | **own small fuse**, gated by GPIO25 |

> The two-buck split is the brownout fix from `power.py`: servos and MCU never
> share a rail, so a 4 A stall spike can't brown out the ESP32.

## Tether conductors (Cat5e or equivalent, 3–5 m)
| Pair | Carries | Gauge note |
|---|---|---|
| 1 + 2 (doubled) | +12 V / GND | use AWG18–20; double up pairs for the power feed |
| 3 | USB-serial (TX/RX) | data |
| 4 | composite video (analog cam) | data |

## Sealing / penetration
All wires enter the **dry head bay** through **one potted gland** in the lid
(marine epoxy). The MS5837 face is **epoxied into the lid sensor port**, gel side
to water. Camera + LED sit **behind the nose window**, inside the dry bay. The 4
servos live in the **flooded** body — buy waterproof servos (or pot them); their
leads run back to the bay gland. See [build_guide.md](build_guide.md) §4, §9.

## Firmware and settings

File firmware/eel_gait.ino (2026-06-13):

/*
 * eel_gait.ino  --  ESP32 anguilliform swim controller.
 *
 * Drives 4 waterproof servos -- 3 front body joints + 1 dive plane --
 * through a PCA9685 16-ch PWM driver to produce a travelling body wave
 * (the rear 2 joints are a passive compliant tail, no servo). This is
 * the firmware port of firmware/gait.py -- keep the two in sync.
 *
 *   theta_i(t) = A_i * sin(2*pi*f*t - phi_i) + heading
 *
 * Hardware:
 *   ESP32 dev board (3V3 logic)
 *   PCA9685 servo driver  (I2C: SDA=21, SCL=22), V+ = servo BEC 5-6V
 *   3x waterproof metal-gear servos on channels 0..2 (front driven joints;
 *       the rear 2 joints are a passive compliant tail, no servo)
 *   1x dive-plane servo on channel 5 (bow planes, active depth control)
 *   MS5837 depth sensor (I2C 0x76) for depth-hold; leak sensor on GPIO34
 *   White LED headlight behind the nose window: logic-level MOSFET gate
 *       on GPIO25 (PWM-dimmed; do NOT drive the LED from the pin directly)
 *   Analog FPV camera: powered from the 5V rail, video goes topside on a
 *       spare tether pair (no firmware involvement)
 *   Power: 12 V down the tether -> robot-local bucks (5-6 V servo bus + a
 *       SEPARATE 5 V MCU buck); USB-serial console on a spare pair.
 *       (Do NOT send 5-6 V down the tether -- see analysis/power.py.)
 *
 * Serial protocol (115200 baud), one command per line:
 *   S <0..1>      set speed scale (0 = stop, 1 = full beat freq)
 *   H <-30..30>   manual steering bias in degrees (turn), heading-hold off
 *   Y <deg>       HOLD heading (closed-loop on the IMU yaw)
 *   M             manual steering (heading-hold off)
 *   D <0..2>      engage depth-hold at target depth (metres)
 *   L             level the dive planes (depth-hold off)
 *   W <0..1>      white headlight brightness (0 = off, 1 = full)
 *   X             emergency stop (center all, freq 0; light stays as set)
 *
 * SAFETY: if the leak sensor trips, the gait halts and all servos centre.
 *
 * Toolchain (pin these -- the source is NOT compile-verified in this repo's CI,
 * which only runs the Python pipeline; treat it as "source updated", compile it
 * yourself before trusting it):
 *   - ESP32 Arduino core 2.0.x   (3.x changed the ledc PWM API used here)
 *   - Adafruit PWM Servo Driver Library  (PCA9685)
 *   - BlueRobotics MS5837 Library  (depth/pressure)
 *   - Wire (bundled)
 *   compile: arduino-cli compile --fqbn esp32:esp32:esp32 firmware/eel_gait.ino
 *
 * STATUS: depth-hold + heading-hold are CLOSED-LOOP but BENCH-UNTESTED.
 * Depth-hold is refused unless the MS5837 inits; heading-hold is refused unless
 * the MPU6050 answers; heading is gyro-only and DRIFTS (add a magnetometer for
 * absolute heading). Treat both as experimental until verified on the bench.
 */

#include <Wire.h>
#include <Adafruit_PWMServoDriver.h>
#include "MS5837.h"                       // BlueRobotics MS5837 depth/pressure

// ---- geometry / gait constants (mirror cad/params.py + firmware/gait.py) ----
// Only the FRONT 3 joints carry servos; the rear 2 are a passive compliant
// tail that flexes to the body wave on its own (no actuator).
const int   N_DRIVEN        = 3;         // driven servos (front joints)
const int   N_BODY_JOINTS   = 5;         // total joints in the body wave
const float JOINT_TRAVEL    = 28.0f;     // deg, mechanical +/- limit
const float CRUISE_AMP_DEG  = 7.0f;      // deg, peak per-joint cruise amplitude
const float BASE_FREQ_HZ    = 2.00f;     // Hz, cruise tail-beat frequency
const float BODY_LENGTH_M   = 0.500f;

// axial stations of the 3 DRIVEN joints (mm) -> phase lags phi_i (rad)
const float JOINT_Z_MM[N_DRIVEN] = {140, 200, 260};
float       PHI[N_DRIVEN];               // filled in setup()
// amplitude envelope A_i (deg): grows toward the tail (over all 5 joints)
float       AMP[N_DRIVEN];

// ---- servo calibration (per channel; tune on the bench) ----
const int   SERVO_CENTER_US = 1500;      // neutral pulse
const float US_PER_DEG      = 10.0f;     // pulse change per command degree
const int   SERVO_MIN_US    = 1000;
const int   SERVO_MAX_US    = 2000;

// ---- dive planes (4th servo, PCA channel 5) ----
const int   DIVE_CH         = 5;         // PCA9685 channel for the dive servo
const float DIVE_MAX_DEG    = 25.0f;     // +/- plane limit (+ = dive)
const float DEPTH_KP        = 12.0f;     // deg per metre of error
const float DEPTH_KD        = 8.0f;      // deg per (m/s)
// water density for the depth conversion -- MUST match params.py WATER:
//   fresh = 997, salt ~ 1029 kg/m^3 (deeper-reading if set too low)
const float FLUID_DENSITY   = 997.0f;    // kg/m^3 (params.WATER = "fresh")

// ---- IMU heading hold (MPU6050 @ I2C 0x68) ----
const int   MPU_ADDR        = 0x68;
const int   MPU_WHOAMI      = 0x75;      // identity register (reads 0x68)
const float GYRO_LSB        = 131.0f;    // LSB per deg/s (+/-250 dps range)
const float HEAD_KP         = 0.6f;      // joint-bias deg per heading-deg error
const float HEAD_KD         = 4.0f;      // deg per (deg/s)
const float HEAD_MAX        = 18.0f;     // max steering bias (deg)

// ---- pins ----
const int   PIN_LEAK        = 34;        // leak probe (HIGH = water detected)
const int   PIN_LED         = 25;        // headlight MOSFET gate (PWM)
const int   LED_CH          = 0;         // LEDC channel for the headlight
const int   LED_PWM_FREQ    = 5000;      // Hz
const int   LED_PWM_BITS    = 8;         // 0..255 duty
const int   PCA_FREQ_HZ     = 50;        // standard analog-servo frame rate

Adafruit_PWMServoDriver pwm = Adafruit_PWMServoDriver(0x40);
MS5837  depthSensor;                     // BlueRobotics MS5837-30BA
bool    g_depthOk = false;               // true once the sensor inits OK
bool    g_imuOk   = false;               // true once the MPU6050 answers

float   g_speed   = 0.0f;                // 0..1 speed scale (start stopped)
float   g_heading = 0.0f;                // deg steering bias
bool    g_estop   = false;
uint32_t g_t0     = 0;

float   g_targetDepth = 0.0f;            // m, commanded depth (0 = surface)
bool    g_depthHold   = false;           // depth-hold engaged?
float   g_prevDepthErr = 0.0f;
uint32_t g_prevDepthMs = 0;

float    g_yaw          = 0.0f;          // integrated heading (deg)
float    g_gyroZbias    = 0.0f;          // calibrated gyro-Z zero (raw LSB)
float    g_targetHeading = 0.0f;
bool     g_headingHold  = false;
float    g_prevHeadErr  = 0.0f;
uint32_t g_prevHeadMs   = 0;
uint32_t g_prevHeadCtrlMs = 0;           // separate timer for the heading PD dt

// Cached depth (metres) from the MS5837. The conversion is blocking (~40 ms),
// so we rate-limit the poll rather than read every control cycle. Returns NAN
// if the sensor never initialised -> callers must treat NAN as "no authority".
float readDepth() {
  static uint32_t lastMs = 0;
  static float cached = 0.0f;
  if (!g_depthOk) return NAN;
  uint32_t now = millis();
  if (now - lastMs >= 100) {              // ~10 Hz sensor poll
    depthSensor.read();
    cached = depthSensor.depth();         // m, uses the set fluid density
    lastMs = now;
  }
  return cached;
}

// PD depth controller -> dive-plane angle (deg, + = dive). No authority at
// zero forward speed (planes need flow), and none without a working sensor.
float diveAngleFromDepth() {
  float depth = readDepth();
  if (isnan(depth)) { g_depthHold = false; return 0.0f; }  // no sensor -> level
  uint32_t now = millis();
  float dt = (now - g_prevDepthMs) / 1000.0f;
  if (dt <= 0.0f) dt = 0.02f;
  g_prevDepthMs = now;
  float err = g_targetDepth - depth;            // +err -> go deeper -> dive
  float derr = (err - g_prevDepthErr) / dt;
  g_prevDepthErr = err;
  float ang = DEPTH_KP * err + DEPTH_KD * derr;
  if (ang >  DIVE_MAX_DEG) ang =  DIVE_MAX_DEG;
  if (ang < -DIVE_MAX_DEG) ang = -DIVE_MAX_DEG;
  return ang;
}

// ---- MPU6050 gyro-Z (yaw) -> heading hold ----
float wrap180(float a){ while(a>180.0f)a-=360.0f; while(a<-180.0f)a+=360.0f; return a; }

int16_t readGyroZraw() {
  Wire.beginTransmission(MPU_ADDR); Wire.write(0x47);   // GYRO_ZOUT_H
  Wire.endTransmission(false);
  Wire.requestFrom(MPU_ADDR, 2, true);
  int16_t v = (Wire.read() << 8) | Wire.read();
  return v;
}

void mpuInit() {
  // identity check FIRST -> gate heading-hold on a real, answering IMU
  Wire.beginTransmission(MPU_ADDR); Wire.write(MPU_WHOAMI);
  if (Wire.endTransmission(false) != 0) { g_imuOk = false; return; }
  Wire.requestFrom(MPU_ADDR, 1, true);
  uint8_t who = Wire.available() ? Wire.read() : 0xFF;
  if (who != 0x68) { g_imuOk = false; return; }    // not an MPU6050 -> no IMU
  Wire.beginTransmission(MPU_ADDR); Wire.write(0x6B); Wire.write(0x00); // wake
  Wire.endTransmission(true);
  delay(50);
  long sum = 0; const int N = 400;                 // calibrate zero (hold still)
  for (int i = 0; i < N; i++) { sum += readGyroZraw(); delay(2); }
  g_gyroZbias = sum / (float)N;
  g_prevHeadMs = millis();
  g_imuOk = true;
}

void updateHeading() {
  if (!g_imuOk) return;                             // no IMU -> yaw stays 0
  uint32_t now = millis();
  float dt = (now - g_prevHeadMs) / 1000.0f;
  if (dt <= 0.0f) dt = 0.02f;
  g_prevHeadMs = now;
  float rateZ = (readGyroZraw() - g_gyroZbias) / GYRO_LSB;   // deg/s
  g_yaw += rateZ * dt;                                       // integrate
}

// PD heading controller -> joint steering bias (deg). Gyro-only yaw drifts;
// add a compass (MPU9250/HMC5883) for absolute long-term heading.
float headingBias() {
  uint32_t now = millis();
  float dt = (now - g_prevHeadCtrlMs) / 1000.0f;
  if (dt <= 0.0f) dt = 0.02f;
  g_prevHeadCtrlMs = now;
  float err = wrap180(g_targetHeading - g_yaw);
  float derr = (err - g_prevHeadErr) / dt;       // deg/s (HEAD_KD units); was
  g_prevHeadErr = err;                            // missing /dt -> rate-dependent
  float b = HEAD_KP * err + HEAD_KD * derr;
  if (b >  HEAD_MAX) b =  HEAD_MAX;               // output saturation
  if (b < -HEAD_MAX) b = -HEAD_MAX;
  return b;
}

// map command angle (deg) -> PCA9685 "tick" (12-bit @ PCA_FREQ_HZ)
int angleToTick(float angle_deg) {
  if (angle_deg >  JOINT_TRAVEL) angle_deg =  JOINT_TRAVEL;
  if (angle_deg < -JOINT_TRAVEL) angle_deg = -JOINT_TRAVEL;
  float us = SERVO_CENTER_US + US_PER_DEG * angle_deg;
  if (us < SERVO_MIN_US) us = SERVO_MIN_US;
  if (us > SERVO_MAX_US) us = SERVO_MAX_US;
  // ticks = us / (1e6 / PCA_FREQ_HZ / 4096)
  float us_per_tick = 1000000.0f / (PCA_FREQ_HZ * 4096.0f);
  return (int)(us / us_per_tick + 0.5f);
}

void centerAll() {
  for (int i = 0; i < N_DRIVEN; i++) pwm.setPWM(i, 0, angleToTick(0.0f));
  pwm.setPWM(DIVE_CH, 0, angleToTick(0.0f));     // dive planes level
}

void setup() {
  Serial.begin(115200);
  pinMode(PIN_LEAK, INPUT);
  ledcSetup(LED_CH, LED_PWM_FREQ, LED_PWM_BITS);   // headlight PWM (core 2.0.x)
  ledcAttachPin(PIN_LED, LED_CH);
  ledcWrite(LED_CH, 0);                  // headlight off at boot
  Wire.begin(21, 22);
  pwm.begin();
  pwm.setPWMFreq(PCA_FREQ_HZ);

  const float k = 2.0f * PI / BODY_LENGTH_M;          // one wave over body
  for (int i = 0; i < N_DRIVEN; i++) {
    PHI[i] = k * (JOINT_Z_MM[i] / 1000.0f);
    // envelope spans all 5 body joints; we drive the front 3 of it
    AMP[i] = CRUISE_AMP_DEG * (0.45f + 0.55f * (i + 1) / (float)N_BODY_JOINTS);
  }
  mpuInit();                              // identity-check + wake + calibrate
  Serial.println(g_imuOk ? "MPU6050 OK" : "MPU6050 FAIL -- heading-hold disabled");
  g_prevHeadCtrlMs = millis();
  // depth sensor: init + report status. Depth-hold is refused unless this is OK
  // (the controller must never act on a fake/zero depth -- that was the old bug)
  depthSensor.setModel(MS5837::MS5837_30BA);
  depthSensor.setFluidDensity(FLUID_DENSITY);    // MUST match params.WATER
  g_depthOk = depthSensor.init();
  Serial.println(g_depthOk ? "MS5837 OK" : "MS5837 FAIL -- depth-hold disabled");
  centerAll();
  g_t0 = millis();
  g_prevDepthMs = millis();
  Serial.println("eel ready: S<spd> H<bias> Y<hdg> M<manual> D<depth> L<level> "
                 "W<light> X<estop>");
}

void readSerial() {
  static char buf[24];
  static uint8_t n = 0;
  while (Serial.available()) {
    char c = Serial.read();
    if (c == '\n' || c == '\r') {
      buf[n] = 0;
      if (n > 0) {
        char cmd = buf[0];
        float val = atof(buf + 1);
        if      (cmd == 'S') { g_speed = constrain(val, 0.0f, 1.0f); g_estop = false; }
        else if (cmd == 'H') { g_heading = constrain(val, -30.0f, 30.0f); g_headingHold = false; }
        else if (cmd == 'Y') {                          // hold heading (IMU only)
          if (g_imuOk) { g_targetHeading = val; g_headingHold = true; }
          else Serial.println("heading-hold unavailable -- MPU6050 not detected");
        }
        else if (cmd == 'M') { g_headingHold = false; }                        // manual steering
        else if (cmd == 'D') {                          // depth-hold (sensor only)
          if (g_depthOk) { g_targetDepth = constrain(val, 0.0f, 2.0f); g_depthHold = true; }
          else Serial.println("depth-hold unavailable -- MS5837 not detected");
        }
        else if (cmd == 'L') { g_depthHold = false; }   // level planes, hold off
        else if (cmd == 'W') {                          // headlight brightness
          float b = constrain(val, 0.0f, 1.0f);
          ledcWrite(LED_CH, (int)(b * 255.0f + 0.5f));
        }
        else if (cmd == 'X') { g_estop = true; }
      }
      n = 0;
    } else if (n < sizeof(buf) - 1) {
      buf[n++] = c;
    }
  }
}

void loop() {
  readSerial();
  updateHeading();                        // integrate IMU yaw every cycle

  // safety: leak -> halt. Debounce (need several consecutive HIGH reads) and
  // LATCH (stay halted until reset) so a noisy probe can't flicker the gait.
  // HW note: AC/pulse-bias the probe rather than DC, and put it at the dry
  // bay's LOWEST point (see docs) -- DC on a wet probe corrodes + false-trips.
  static uint8_t leakCount = 0;
  static bool leakLatched = false;
  if (digitalRead(PIN_LEAK) == HIGH) { if (leakCount < 5) leakCount++; }
  else if (leakCount > 0) leakCount--;
  if (leakCount >= 5 && !leakLatched) {
    leakLatched = true;
    Serial.println("!! LEAK -- halting (latched; reset to clear)");
  }
  if (leakLatched) g_estop = true;

  if (g_estop || g_speed <= 0.0f) {
    centerAll();
    delay(20);
    return;
  }

  // closed-loop heading: IMU yaw error -> steering bias (overrides manual)
  float steer = g_headingHold ? headingBias() : g_heading;

  float t = (millis() - g_t0) / 1000.0f;
  float f = BASE_FREQ_HZ * g_speed;
  for (int i = 0; i < N_DRIVEN; i++) {                   // front 3 driven servos
    float ang = AMP[i] * sinf(2.0f * PI * f * t - PHI[i]) + steer;
    pwm.setPWM(i, 0, angleToTick(ang));
  }
  // bow dive planes: depth-hold PID if engaged, else level
  float dive = g_depthHold ? diveAngleFromDepth() : 0.0f;
  pwm.setPWM(DIVE_CH, 0, angleToTick(dive));
  delay(15);                                            // ~66 Hz update
}

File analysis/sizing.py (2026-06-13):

"""
sizing.py  --  First-order physics & sizing for the eel robot.

Pulls every geometric input from cad/params.py so the math always
matches the CAD. Computes, prints, and saves a report covering:

  1. Geometry        : displaced volume, wetted area, frontal area
  2. Buoyancy/ballast: neutral-buoyancy mass budget
  3. Hydrodynamics   : cruise drag, thrust, propulsive power
  4. Gait (Strouhal) : tail-beat frequency, per-joint phase offsets
  5. Actuation       : per-joint servo torque demand vs rated
  6. Power/energy    : electrical budget, battery / tether current

All results are ORDER-OF-MAGNITUDE engineering estimates with the
assumptions printed alongside. Treat as design targets, refine with
CFD (analysis stage D) and bench tests.

Run:  python sizing.py
"""

import os
import sys
import math
import numpy as np

# import the shared parameter module from ../cad
sys.path.insert(0, os.path.join(os.path.dirname(os.path.abspath(__file__)),
                                "..", "cad"))
import params as P   # noqa: E402


# ----------------------------------------------------------------------
# assumptions you may want to tune
# ----------------------------------------------------------------------
ENDURANCE_TARGET_MIN = 30.0    # min of active swimming we size energy for
PROP_EFFICIENCY      = 0.40    # undulatory propulsive efficiency (0.2-0.5)
SHELL_PACKING        = 0.50    # printed-shell effective fill (infill+walls)
CD_PLATE             = 1.2     # flat-plate normal drag coeff (segment sweep)
HOTEL_W              = 2.0     # W, electronics always-on (MCU+sensors+leak)
SERVO_AVG_W_EACH     = 0.8     # W, average per DRIVEN servo while beating
DIVE_SERVO_W         = 0.3     # W, dive-plane servo (mostly holding position)

# mass line-items (kg) -- swap for measured values as you buy parts
M_SERVO_EACH = 0.014           # 9-14 g metal-gear micro (MG90S class, potted)
M_BATTERY    = 0.030           # small 2S buffer pack (tether supplies bulk)
M_ELECTRONICS = 0.055          # MCU + driver + IMU + depth + leak + FPV
                               # camera + LED headlight + MOSFET + window
M_HARDWARE   = 0.020           # pins, screws, inserts
M_SKIN_FIN   = 0.085           # TPU sleeve (~72 g) + tail fin foil
M_DIVE       = 0.026           # 2 dive planes + transverse shaft


def rho_water():
    return P.RHO_FRESH if P.WATER == "fresh" else P.RHO_SALT


# ----------------------------------------------------------------------
# 1. GEOMETRY  (integrate the body of revolution)
# ----------------------------------------------------------------------
def geometry():
    samples = P.body_wetted_radius_list(400)
    # the nose is truncated at the camera window -> body starts at WINDOW_Z
    z0 = P.WINDOW_Z / 1000.0
    samples = [s for s in samples if s[0] >= z0]
    z = np.array([s[0] for s in samples])          # m
    r = np.array([s[1] for s in samples])          # m
    # displaced volume  V = integral pi r^2 dz
    vol = float(np.trapezoid(math.pi * r ** 2, z))
    # wetted area  A = integral 2 pi r sqrt(1 + (dr/dz)^2) dz
    drdz = np.gradient(r, z)
    area = float(np.trapezoid(2 * math.pi * r * np.sqrt(1 + drdz ** 2), z))
    return dict(volume=vol, wetted=area, frontal=P.frontal_area())


# ----------------------------------------------------------------------
# 2. MASS / BUOYANCY BUDGET
# ----------------------------------------------------------------------
def head_bay_volume():
    """Displaced volume (m^3) of the sealed head bay (WINDOW_Z..HEAD_LEN)."""
    n = 120
    zs = np.linspace(P.WINDOW_Z / 1000.0, P.HEAD_LEN / 1000.0, n)
    rs = np.array([P.radius_profile(z * 1000.0) / 1000.0 for z in zs])
    return float(np.trapezoid(math.pi * rs ** 2, zs))


def mass_budget(geo):
    shell = geo["wetted"] * (P.WALL / 1000.0) * P.RHO_PLA * SHELL_PACKING
    n_servo = P.N_DRIVEN + 1                           # 3 driven joints + 1 dive
    servos = n_servo * M_SERVO_EACH
    parts = {
        "shell (PLA)":   shell,
        "servos x%d" % n_servo: servos,
        "battery":       M_BATTERY,
        "electronics":   M_ELECTRONICS,
        "hardware":      M_HARDWARE,
        "skin+tailfin":  M_SKIN_FIN,
        "dive planes":   M_DIVE,
    }
    dry = sum(parts.values())
    displaced = geo["volume"] * rho_water()          # kg, FULLY-SEALED body
    ballast = displaced - dry                         # +ve => add ballast
    # free-flooding option: only the head bay traps air; flooded tail
    # segments displace ~ their solid (PLA) volume only ~= shell mass / rho.
    # free-flood displacement = head-bay air + shell material + buoyancy FOAM
    foam_disp = (P.FOAM_VOL / 1e6) * rho_water()          # kg, stability foam
    disp_flood = head_bay_volume() * rho_water() + shell + foam_disp
    ballast_flood = disp_flood - dry                      # = the lead KEEL
    return (parts, dry, displaced, ballast, disp_flood, ballast_flood)


# ----------------------------------------------------------------------
# 3. HYDRODYNAMICS  (cruise)
# ----------------------------------------------------------------------
def hydro(geo):
    v = P.DESIGN_SPEED
    Fd = 0.5 * rho_water() * P.CD_AXIAL * geo["frontal"] * v ** 2
    P_thrust = Fd * v                                 # ideal thrust power
    P_prop = P_thrust / PROP_EFFICIENCY               # mech power into water
    return dict(drag=Fd, thrust=Fd, p_thrust=P_thrust, p_prop=P_prop)


# ----------------------------------------------------------------------
# 4. GAIT  (Strouhal -> frequency + traveling-wave phases)
# ----------------------------------------------------------------------
def gait():
    v = P.DESIGN_SPEED
    A = P.TAIL_AMPLITUDE                               # m, target lateral sweep
    f = P.CRUISE_FREQ_HZ                               # Hz, chosen tail-beat
    # traveling wave: one wavelength ~ body length -> phase per axial mm
    wavelength = P.BODY_LENGTH / 1000.0                # m
    k = 2 * math.pi / wavelength                       # rad/m
    phases = []
    for i, z in enumerate(P.JOINT_Z):
        phi = k * (z / 1000.0)                          # rad lag at this joint
        phases.append((i + 1, z, math.degrees(phi) % 360.0))
    return dict(freq=f, amplitude=A, phases=phases,
                omega_pk=2 * math.pi * f * math.radians(P.JOINT_TRAVEL_DEG))
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

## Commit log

2026-06-13 Initial commit: bio-inspired underwater eel robot (complete digital design package)
    Parametric CAD + first-principles analysis + ESP32 firmware + build docs + BOM. Pipeline self-checks 28/28 via verify_all.py. Verified digital prototype; physical build steps (compile, buy, print, se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
    [cfd_hull.step, cfd_hull.stl, coupon_oring_bore.stl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]
2026-06-13 Add GitHub landing README (links to report, viewer, build docs)
2026-06-13 Add animated swim+dive demo GIF to README (rendered from CAD via render_anim.py)
2026-06-13 Replace demo with HyperFrames render: forward motion, depth rings, see-through internals, dive
    Seek-driven Three.js composition reusing the viewer's scene (cad/make_video.py); rendered to MP4 + GIF. Adds the motion + internals the matplotlib GIF lacked.
    [make_video.py]
2026-06-13 Fix lead keel poking out the nose: compact block behind the nose face
    Keel box was 85mm centred at z=40 -> front spiked ~20mm past the nose window. Reshaped to a compact 26x16x42 block (same lead volume, same centroid) so it tucks under the body; stability math unchanged (uses centroid). Re-rendered viewer + demo video.
    [cfd_hull.step, eel_straight.step, eel_swim.step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]
2026-06-14 Polish docs/comments and remove the review-thread doc
2026-06-14 Add interactive 3D viewers + landing page at repo root (open directly / via GitHub Pages)
2026-06-14 Exclude generated CAD meshes (stl/step) from language stats too
